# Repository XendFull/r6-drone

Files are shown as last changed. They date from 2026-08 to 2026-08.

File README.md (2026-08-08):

# ESP32-CAM WiFi Robot

A WiFi-controlled robot built on an ESP32-CAM (AI-Thinker) with live video streaming and independent per-motor speed control over WebSockets, driven from a custom tactical HUD-style browser control panel.

## Demo

[YouTube link]

## Features

- Live MJPEG camera stream, served directly from the ESP32-CAM (no extra server needed)
- Real-time motor control over WebSocket (port 81), independent from the video HTTP server (port 80)
- Independent PWM speed control per motor (-255 to +255, sign = direction)
- Browser-based control panel with:
  - Live video feed with animated HUD-style corner brackets
  - Two vertical throttle sliders (Motor A / Motor B)
  - LINK mode to drive both motors together as one throttle
  - Emergency stop
  - Editable device IP (no code editing needed to connect)

## Hardware

| Component | Notes |
|---|---|
| ESP32-CAM (AI-Thinker) | Main controller + camera |
| DRV8833 motor driver | Dual H-bridge for 2 DC motors |
| 2x DC motors | Left/right drive |
| Separate motor power supply | See "Power" note below — do **not** share the ESP32-CAM's supply with the motors |

### Wiring

| DRV8833 pin | ESP32-CAM GPIO |
|---|---|
| IN1 | GPIO14 |
| IN2 | GPIO15 |
| IN3 | GPIO13 |
| IN4 | GPIO12 |

> **Note:** GPIO12 is a boot strapping pin on the ESP32. It defaults LOW at boot, which works fine here, but avoid any wiring that could pull it HIGH during power-up, or the board may fail to boot.

### Power

The ESP32-CAM's WiFi radio is sensitive to voltage sag. Running motors off the **same** supply as the ESP32-CAM can brown out the board the instant a motor kicks on, killing the video stream and WebSocket connection simultaneously.

Recommended:
- Separate battery for motors vs. ESP32-CAM logic, with only grounds tied together, **or**
- At minimum, a large bulk capacitor (1000µF+) across the motor supply near the DRV8833, and another (470–1000µF) at the ESP32-CAM's 5V input

## Firmware setup

1. Open `ESP32_CAM_Robot.ino` in Arduino IDE.
2. Set your WiFi credentials:
   ```cpp
   const char* ssid     = "YOUR_SSID";
   const char* password = "YOUR_PASSWORD";
   ```
3. Board settings: **AI Thinker ESP32-CAM**, partition scheme with enough space for the camera app (e.g. "Huge APP").
4. Flash with GPIO0 grounded (flashing mode), then reset with GPIO0 disconnected to run normally.
5. Open Serial Monitor at 115200 baud — it will print the assigned IP address once connected to WiFi.

## Control panel setup

1. Open `control_panel.html` in any browser (double-click it, or serve it locally — no build step required).
2. Type your ESP32's IP address (shown in Serial Monitor) into the **DEVICE IP** field (line 351) and tap **SET**.
3. Video feed and motor sliders will connect automatically.

Make sure the device you're using the control panel from is on the **same WiFi network** as the ESP32-CAM.

## WebSocket command protocol

Sent as plain text over the WebSocket connection on port 81:

| Command | Effect |
|---|---|
| `A:<int>` | Set Motor A speed, -255 (full reverse) to 255 (full forward) |
| `B:<int>` | Set Motor B speed, -255 to 255 |
| `STOP` | Stop both motors immediately |

## Challenges solved

- **WebSocket handshake never completing**: caused by a blocking `delay()` in the main loop preventing `webSocket.loop()` from running often enough to process the HTTP upgrade handshake in time.
- **Camera + controls freezing together under motor load**: a power brownout — the motors drawing current caused the ESP32's WiFi radio to drop momentarily. Fixed with a separate motor power supply and bulk capacitors.

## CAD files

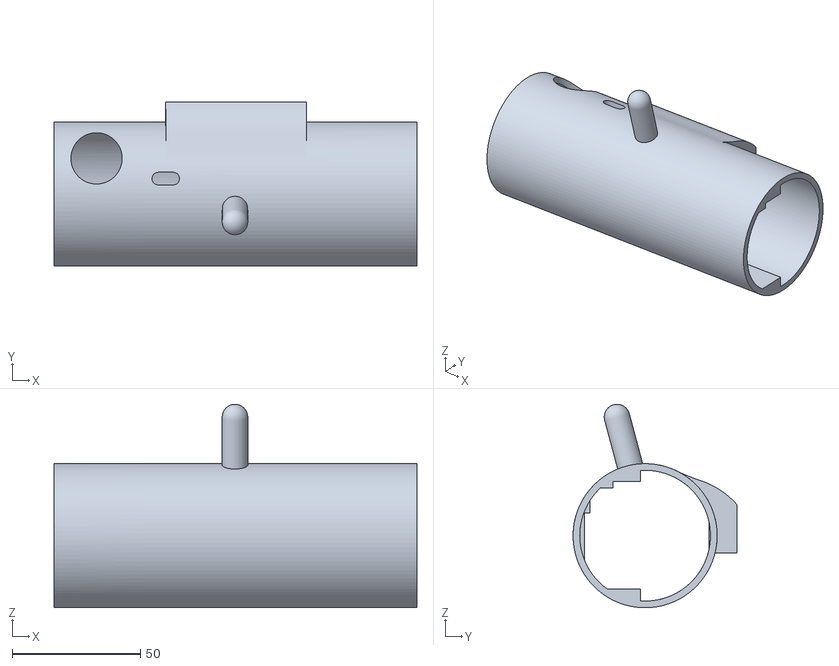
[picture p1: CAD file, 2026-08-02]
cad/DRONE_outer.stl
141.6 x 63.9 x 79.4

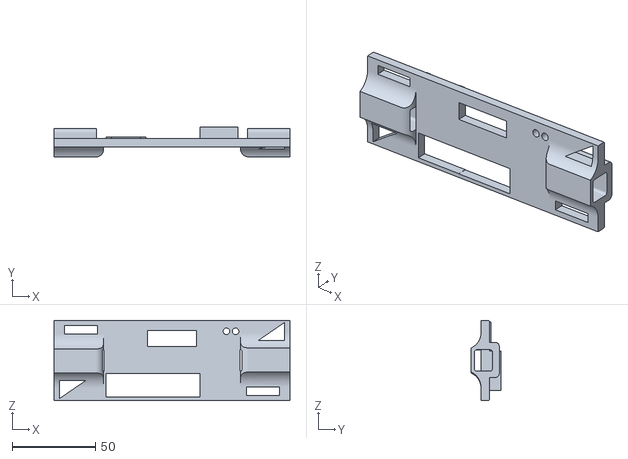
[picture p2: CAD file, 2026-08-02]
cad/DRONE_inner.stl
142.0 x 18.0 x 48.2

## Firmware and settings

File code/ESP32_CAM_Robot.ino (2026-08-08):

/*
 * ESP32-CAM (AI-Thinker) — Camera stream (port 80) + WebSocket motor control (port 81)
 *
 * Motor driver: DRV8833
 *   IN1 = GPIO14
 *   IN2 = GPIO15
 *   IN3 = GPIO13
 *   IN4 = GPIO12
 *
 * Requires: "ESP32" board package, "WebSockets" library by Markus Sattler (Links2004)
 *
 * NOTE ON GPIO12: this is a boot strapping pin. It defaults LOW at boot, which is fine for
 * most DRV8833 wiring, but avoid anything that could pull it HIGH during power-up/reset,
 * or the board may fail to boot correctly.
 */

#include "esp_camera.h"
#include <WiFi.h>
#include <WebSocketsServer.h>
#include "esp_http_server.h"

// ============ WiFi credentials ============
const char* ssid     = "********";
const char* password = "********";

// ============ AI-Thinker camera pin map ============
#define PWDN_GPIO_NUM     32
#define RESET_GPIO_NUM    -1
#define XCLK_GPIO_NUM      0
#define SIOD_GPIO_NUM     26
#define SIOC_GPIO_NUM     27
#define Y9_GPIO_NUM       35
#define Y8_GPIO_NUM       34
#define Y7_GPIO_NUM       39
#define Y6_GPIO_NUM       36
#define Y5_GPIO_NUM       21
#define Y4_GPIO_NUM       19
#define Y3_GPIO_NUM       18
#define Y2_GPIO_NUM        5
#define VSYNC_GPIO_NUM    25
#define HREF_GPIO_NUM     23
#define PCLK_GPIO_NUM     22

// ============ Motor driver pins (DRV8833) ============
#define IN1 14
#define IN2 15
#define IN3 13
#define IN4 12

// ============ PWM speed control ============
const int PWM_FREQ = 5000;
const int PWM_RES  = 8;      // 8-bit -> duty range 0-255

WebSocketsServer webSocket = WebSocketsServer(81);
httpd_handle_t index_httpd = NULL;

// ---------------- Minimal HTML control/preview page ----------------
static const char INDEX_HTML[] PROGMEM = R"HTML(
<!DOCTYPE html><html><head><title>ESP32-CAM Robot</title></head>
<body style="text-align:center;font-family:sans-serif;">
<h2>ESP32-CAM Robot</h2>
<img src="/stream" style="width:90%;max-width:480px;border:1px solid #333;">
</body></html>
)HTML";

static esp_err_t index_handler(httpd_req_t *req) {
  httpd_resp_set_type(req, "text/html");
  return httpd_resp_send(req, INDEX_HTML, strlen(INDEX_HTML));
}

// ---------------- MJPEG stream handler ----------------
#define PART_BOUNDARY "123456789000000000000987654321"
static const char *STREAM_CONTENT_TYPE = "multipart/x-mixed-replace;boundary=" PART_BOUNDARY;
static const char *STREAM_BOUNDARY = "\r\n--" PART_BOUNDARY "\r\n";
static const char *STREAM_PART = "Content-Type: image/jpeg\r\nContent-Length: %u\r\n\r\n";

static esp_err_t stream_handler(httpd_req_t *req) {
  camera_fb_t *fb = NULL;
  esp_err_t res = ESP_OK;
  char part_buf[64];

  res = httpd_resp_set_type(req, STREAM_CONTENT_TYPE);
  if (res != ESP_OK) return res;

  while (true) {
    fb = esp_camera_fb_get();
    if (!fb) {
      Serial.println("Camera capture failed");
      res = ESP_FAIL;
    } else {
      if (fb->format != PIXFORMAT_JPEG) {
        Serial.println("Non-JPEG frame skipped");
        esp_camera_fb_return(fb);
        continue;
      }
      size_t hlen = snprintf(part_buf, sizeof(part_buf), STREAM_PART, fb->len);
      if (res == ESP_OK) res = httpd_resp_send_chunk(req, STREAM_BOUNDARY, strlen(STREAM_BOUNDARY));
      if (res == ESP_OK) res = httpd_resp_send_chunk(req, part_buf, hlen);
      if (res == ESP_OK) res = httpd_resp_send_chunk(req, (const char *)fb->buf, fb->len);
      esp_camera_fb_return(fb);
    }
    if (res != ESP_OK) break;
  }
  return res;
}

void startCameraServer() {
  httpd_config_t config = HTTPD_DEFAULT_CONFIG();
  config.server_port = 80;
  config.ctrl_port = 32768;

  httpd_uri_t index_uri = { .uri = "/", .method = HTTP_GET, .handler = index_handler, .user_ctx = NULL };
  httpd_uri_t stream_uri = { .uri = "/stream", .method = HTTP_GET, .handler = stream_handler, .user_ctx = NULL };

  if (httpd_start(&index_httpd, &config) == ESP_OK) {
    httpd_register_uri_handler(index_httpd, &index_uri);
    httpd_register_uri_handler(index_httpd, &stream_uri);
  }
}

// ---------------- Motor control (independent per-motor PWM speed) ----------------
// speed range: -255 (full reverse) to +255 (full forward), 0 = stop
void setMotorA(int speed) {
  speed = constrain(speed, -255, 255);
  if (speed >= 0) { ledcWrite(IN1, speed); ledcWrite(IN2, 0); }
  else            { ledcWrite(IN1, 0);     ledcWrite(IN2, -speed); }
}

void setMotorB(int speed) {
  speed = constrain(speed, -255, 255);
  if (speed >= 0) { ledcWrite(IN3, speed); ledcWrite(IN4, 0); }
  else            { ledcWrite(IN3, 0);     ledcWrite(IN4, -speed); }
}

void stopMotors() {
  setMotorA(0);
  setMotorB(0);
}

// ---------------- WebSocket event handler ----------------
void webSocketEvent(uint8_t num, WStype_t type, uint8_t *payload, size_t length) {
  switch (type) {
    case WStype_DISCONNECTED:
      Serial.printf("[%u] Disconnected\n", num);
      stopMotors();  // safety: stop if the link drops
      break;

    case WStype_CONNECTED: {
      IPAddress ip = webSocket.remoteIP(num);
      Serial.printf("[%u] Client connected from %u.%u.%u.%u\n", num, ip[0], ip[1], ip[2], ip[3]);
      webSocket.sendTXT(num, "CONNECTED");
      break;
    }

    case WStype_TEXT: {
      String cmd = String((char*)payload).substring(0, length);
      Serial.printf("[%u] Command: %s\n", num, cmd.c_str());
      if      (cmd == "S" || cmd == "STOP") stopMotors();
      else if (cmd.startsWith("A:")) {
        setMotorA(cmd.substring(2).toInt());
      }
      else if (cmd.startsWith("B:")) {
        setMotorB(cmd.substring(2).toInt());
      }
      break;
    }

    default:
      break;
  }
}

void setup() {
  Serial.begin(115200);
  Serial.setDebugOutput(false);

  ledcAttach(IN1, PWM_FREQ, PWM_RES);
  ledcAttach(IN2, PWM_FREQ, PWM_RES);
  ledcAttach(IN3, PWM_FREQ, PWM_RES);
  ledcAttach(IN4, PWM_FREQ, PWM_RES);
  stopMotors();

  // ---------------- Camera init ----------------
  camera_config_t config;
  config.ledc_channel = LEDC_CHANNEL_0;
  config.ledc_timer   = LEDC_TIMER_0;
  config.pin_d0 = Y2_GPIO_NUM;
  config.pin_d1 = Y3_GPIO_NUM;
  config.pin_d2 = Y4_GPIO_NUM;
  config.pin_d3 = Y5_GPIO_NUM;
  config.pin_d4 = Y6_GPIO_NUM;
  config.pin_d5 = Y7_GPIO_NUM;
  config.pin_d6 = Y8_GPIO_NUM;
  config.pin_d7 = Y9_GPIO_NUM;
  config.pin_xclk = XCLK_GPIO_NUM;
  config.pin_pclk = PCLK_GPIO_NUM;
  config.pin_vsync = VSYNC_GPIO_NUM;
  config.pin_href = HREF_GPIO_NUM;
  config.pin_sscb_sda = SIOD_GPIO_NUM;
  config.pin_sscb_scl = SIOC_GPIO_NUM;
  config.pin_pwdn = PWDN_GPIO_NUM;
  config.pin_reset = RESET_GPIO_NUM;
  config.xclk_freq_hz = 20000000;
  config.frame_size = FRAMESIZE_VGA;
  config.pixel_format = PIXFORMAT_JPEG;
  config.grab_mode = CAMERA_GRAB_WHEN_EMPTY;
  config.fb_location = CAMERA_FB_IN_PSRAM;
  config.jpeg_quality = 12;
  config.fb_count = 1;

  if (psramFound()) {
    config.jpeg_quality = 10;
    config.fb_count = 2;
    config.grab_mode = CAMERA_GRAB_LATEST;
  } else {
    config.frame_size = FRAMESIZE_SVGA;
    config.fb_location = CAMERA_FB_IN_DRAM;
  }

  esp_err_t err = esp_camera_init(&config);
  if (err != ESP_OK) {
    Serial.printf("Camera init failed with error 0x%x\n", err);
    return;
  }

  // ---------------- WiFi ----------------
  // IMPORTANT: disable power-save so incoming packets (WS handshake + motor
  // commands) aren't delayed by radio sleep cycles.
  WiFi.setSleep(false);
  WiFi.begin(ssid, password);
  Serial.print("WiFi connecting");
  while (WiFi.status() != WL_CONNECTED) {
    delay(300);
    Serial.print(".");
  }
  Serial.println();
  Serial.println("WiFi connected");
  Serial.print("Camera stream ready: http://");
  Serial.println(WiFi.localIP());

  startCameraServer();

  // ---------------- WebSocket ----------------
  webSocket.begin();
  webSocket.onEvent(webSocketEvent);
  Serial.println("WS READY on port 81");
}

void loop() {
  // MUST be called every pass with no blocking delay before/after it,
  // or the WebSocket handshake will time out on the client side.
  webSocket.loop();
}
